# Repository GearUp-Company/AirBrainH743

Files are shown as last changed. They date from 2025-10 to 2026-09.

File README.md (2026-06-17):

<h1>
  <picture>
    <source media="(prefers-color-scheme: dark)" srcset="datasheet/Gearup_White.png">
    <source media="(prefers-color-scheme: light)" srcset="datasheet/Gearup.png">
    GearUp Logo
  </picture>
  AirBrainH743
</h1>

GearUp **AirBrain H743** flight controller. STM32H743VIH6 (480 MHz Cortex-M7), 36 × 31 × 10 mm, 8 g. Designed and made in Belgium.

This repository hosts the datasheet, pinouts, mechanical resources, and integration guides for the board. Source-of-truth for the product is the [Airbrain product page](https://takeyourgear.com/pages/products/airbrain).

<div align="center">

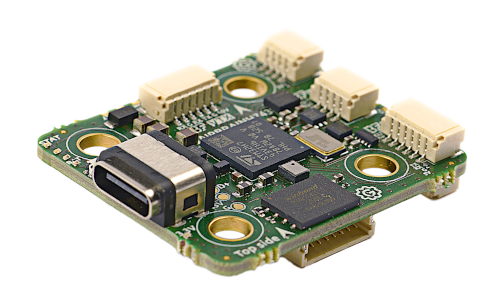
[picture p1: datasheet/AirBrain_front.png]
AirBrain_Front


</div>

## Firmware support

The AirBrain H743 is **officially supported upstream** by Betaflight, ArduPilot, and PX4. Targets live in each project's main branch.

| Stack | Target | Canonical source |
|---|---|---|
| **Betaflight** | `AIRBRAINH743` | Betaflight Configurator, Firmware Flasher, board dropdown |
| **ArduPilot** | `AIRBRAINH743` | Latest builds for [Copter](https://firmware.ardupilot.org/Copter/latest/AIRBRAINH743/), [Plane](https://firmware.ardupilot.org/Plane/latest/AIRBRAINH743/), [Rover](https://firmware.ardupilot.org/Rover/latest/AIRBRAINH743/), [Sub](https://firmware.ardupilot.org/Sub/latest/AIRBRAINH743/) |
| **PX4** | `gearup_airbrainh743_default` | [Latest CI build (.px4)](https://px4-travis.s3.amazonaws.com/Firmware/master/gearup_airbrainh743_default.px4) |

Boards ship pre-flashed with **Betaflight**.

INAV is in beta. Targets are present in this repo's `firmware/INAV/` folder for testing.

## Pinout & Datasheet

Latest datasheet and pinouts: [`/datasheet`](/datasheet).

<div align="center">

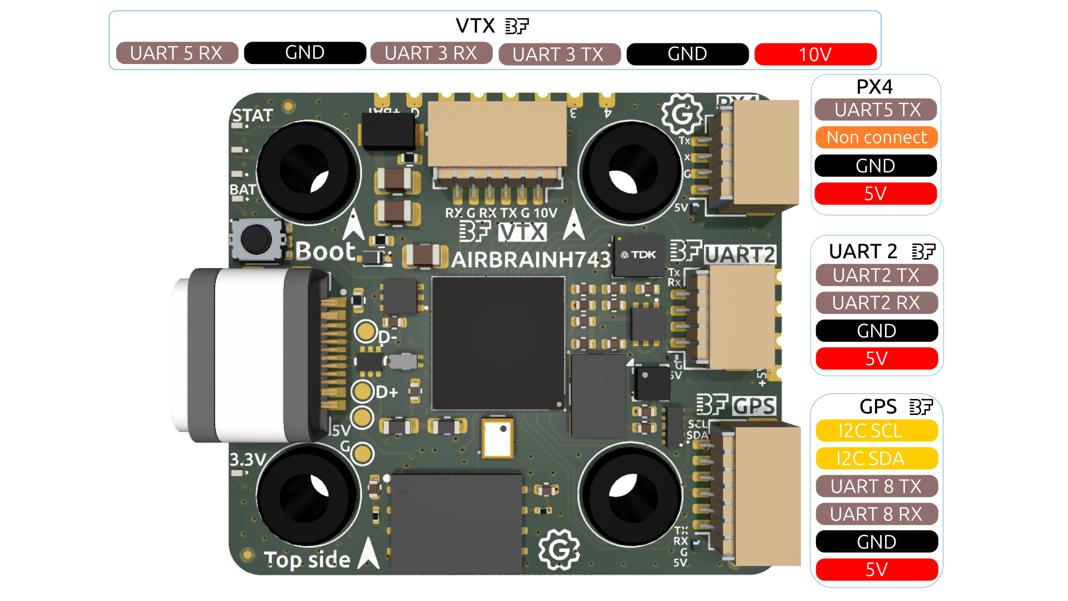
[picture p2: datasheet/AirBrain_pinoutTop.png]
AirBrain_Pinout_top

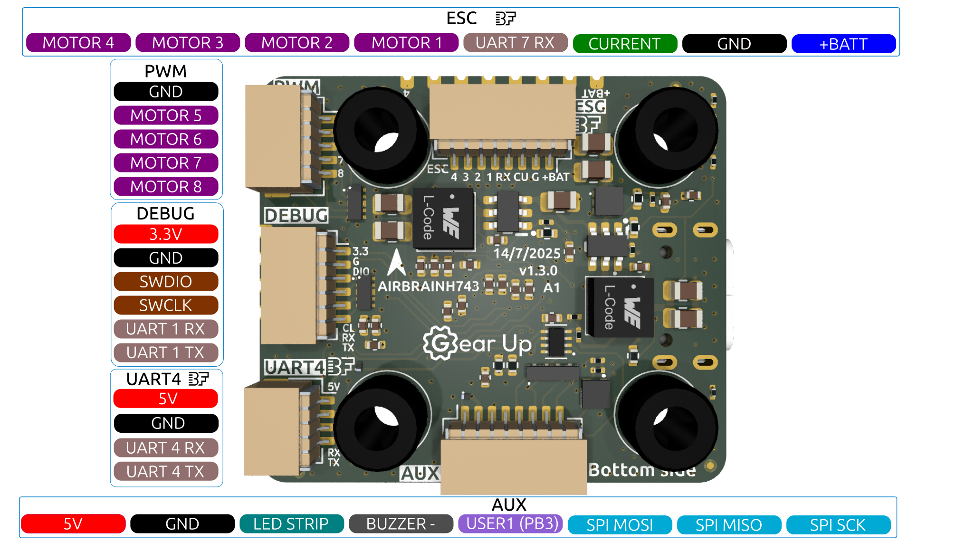
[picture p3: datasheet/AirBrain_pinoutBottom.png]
AirBrain_Pinout_bottom


</div>

## Switching firmware stacks

Boards ship with Betaflight. Switching to ArduPilot or PX4 is a one-time operation on a desktop computer. After switching, you can switch back with the same procedure.

### Entering DFU mode

DFU (Device Firmware Update) is the STM32's built-in ROM bootloader. It's required for the first install of any firmware family, for switching bootloaders (PX4, ArduPilot), and for recovery. Two routes into DFU:

- **Hardware (BOOT button)**: hold the on-board **BOOT** button while plugging in the USB cable. Release after the board enumerates. This route works regardless of which firmware is currently on the board, including a bricked board.
- **From Betaflight Configurator**: with Betaflight running, click **Activate Boot Loader** in the top right. The board reboots into DFU. *Only works while Betaflight is running.* If the board has ArduPilot or PX4 on it, use the BOOT button.

In DFU mode the board enumerates as a USB DFU device ("STM32 BOOTLOADER" or "DFU in FS Mode") and no longer responds as a serial device until you flash and exit.

---

### Betaflight, to ArduPilot

ArduPilot uses its **own bootloader** (different from Betaflight's monolithic flash layout). For a clean first install on an AirBrain that's running Betaflight, we recommend flashing the **with-bootloader** ArduPilot variant first; subsequent updates can use the no-bootloader `.apj` via Mission Planner over USB-MAVLink.

1. Go to [firmware.ardupilot.org/Copter/latest/AIRBRAINH743/](https://firmware.ardupilot.org/Copter/latest/AIRBRAINH743/) (replace `Copter` with `Plane`, `Rover`, `Sub`, etc. for your vehicle type).
2. Two files are published per release (vehicle-prefixed, e.g. `arducopter`, `arduplane`):
   - `<vehicle>_with_bl.hex`: contains the ArduPilot bootloader **and** firmware as a multi-region Intel HEX file. Use this for the first flash from a Betaflight board.
   - `<vehicle>.apj`: firmware only. Use this for over-MAVLink updates once the ArduPilot bootloader is on the board.
3. Put the AirBrain in **DFU mode** (BOOT button + USB).
4. Open **Mission Planner** (or QGroundControl).
5. Use the GCS's custom-firmware install option and select the `_with_bl.hex` file. Follow the on-screen prompts.
6. Wait for the flash to complete. The board reboots into ArduPilot.

For subsequent ArduPilot version bumps, you can connect the GCS to the running ArduPilot board over USB and flash the no-bootloader `.apj` directly.

---

### Betaflight, to PX4

PX4 uses its **own bootloader**, distinct from the Betaflight/ArduPilot bootloader. So switching to PX4 is a two-step flash: bootloader, then firmware.

#### Step 1: Flash the PX4 bootloader

Get the PX4 bootloader binary from this repo: [`firmware/PX4/bin/bootloader/gearup_airbrainh743_bootloader.bin`](firmware/PX4/bin/bootloader/gearup_airbrainh743_bootloader.bin).

Pick whichever flashing tool you're most comfortable with. The board needs to be in **DFU mode** for all three.

##### Option A: Betaflight Configurator (cross-platform, GUI)

Betaflight Configurator's Firmware Flasher can load any local `.bin` and write it via the STM32 ROM DFU. Works in both the desktop app and the web Configurator at [app.betaflight.com](https://app.betaflight.com).

1. Open Betaflight Configurator.
2. Put the AirBrain in DFU mode (see "Entering DFU mode" above).
3. Go to the **Firmware Flasher** tab.
4. Click **Load Firmware [Local]** and select `gearup_airbrainh743_bootloader.bin`.
5. Click **Flash Firmware**.

> Reported to work by upstream maintainers; not yet self-verified by GearUp end-to-end. If it fails, fall back to Option B (STM32CubeProgrammer) or Option C (dfu-util).

##### Option B: STM32CubeProgrammer (official ST tool, GUI, cross-platform)

[Download STM32CubeProgrammer](https://www.st.com/en/development-tools/stm32cubeprog.html) from ST.

1. Put the AirBrain in DFU mode.
2. Open STM32CubeProgrammer.
3. Connection dropdown (top right): select **USB**, then your DFU device, click **Connect**.
4. Click the **Erasing & Programming** tab on the left.
5. Browse to `gearup_airbrainh743_bootloader.bin`.
6. Set start address to `0x08000000`.
7. Click **Start Programming**.

##### Option C: dfu-util (CLI, Linux/macOS)

```sh
dfu-util -a 0 -s 0x08000000:leave \
  -D gearup_airbrainh743_bootloader.bin
```

#### Step 2: Flash the PX4 firmware

After flashing the bootloader, the board reboots and enumerates as a PX4 device. Two routes work, pick whichever fits your setup.

##### Option A: QGC Daily, Developer Build (recommended until PX4 v1.18 stable)

The AirBrain H743 target is on PX4 main branch but not yet in PX4 stable (v1.17). Until v1.18 lands, the cleanest route is QGC Daily, which auto-downloads the latest build from main.

1. Download QGC Daily from [docs.qgroundcontrol.com/Stable_V5.0/en/qgc-user-guide/releases/daily_builds.html](https://docs.qgroundcontrol.com/Stable_V5.0/en/qgc-user-guide/releases/daily_builds.html).
2. Open QGC Daily, go to **Vehicle Configuration, Firmware**, pick the USB port, click **Flash**.
3. Unplug and replug the USB cable when prompted.
4. Select **Advanced Settings**, choose **Developer Build (master)**.
5. QGC pulls the latest .px4 from PX4 main and flashes it.

After PX4 v1.18 stable releases (expected later in 2026), QGC Stable will pick the AirBrain target automatically. We will update this section then.

##### Option B: Manual download

For air-gapped systems or when you want a specific build pinned.

1. Download the latest PX4 firmware: [gearup_airbrainh743_default.px4](https://px4-travis.s3.amazonaws.com/Firmware/master/gearup_airbrainh743_default.px4). This is the official PX4 CI build, automatically rebuilt from PX4 main branch.
2. Open QGroundControl.
3. Connect the AirBrain via USB.
4. Use **Vehicle Setup, Firmware**, click **Advanced Settings**, choose **Custom firmware file**.
5. Select the .px4 file you downloaded.
6. Wait for the flash to complete.

> **Internal magnetometer note.** The LIS2MDL chip is detected by PX4 iis2mdc driver out of the box. PX4 dmesg should show iis2mdc #0 on I2C bus 1 address 0x1E rotation 2. No board-config change required. Verified 2026-06-16 with PX4 contributor Julian Oes.

---

### ArduPilot or PX4, back to Betaflight

Betaflight is a monolithic image flashed directly at `0x08000000` via STM32 ROM DFU. Going back from ArduPilot or PX4 wipes the previous bootloader and replaces it with Betaflight in one operation.

The "Activate Boot Loader" button in Betaflight Configurator only exists when Betaflight is already running. From ArduPilot or PX4 you must use the **hardware BOOT button** to enter DFU.

1. Put the AirBrain in DFU mode (hold BOOT button + plug in USB).
2. Open **Betaflight Configurator** (desktop app or web Configurator at [app.betaflight.com](https://app.betaflight.com)).
3. Go to the **Firmware Flasher** tab.
4. Select target `AIRBRAINH743` from the dropdown.
5. Pick the latest stable Betaflight release.
6. Check **Full chip erase** (recommended; clears any leftover ArduPilot bootloader area or PX4 NAND filesystem state).
7. Click **Load Firmware [Online]**, then **Flash Firmware**.

GearUp has a **cloud-build partnership integration in Betaflight Configurator**, so AirBrain targets are available in the official Configurator dropdown without any extra setup.

> **Offline recovery**: if Betaflight Configurator's online flasher is unavailable, the factory-default Betaflight binary is at [`firmware/Betaflight/bin/airbrain_h743_factory_recovery.bin`](firmware/Betaflight/bin/airbrain_h743_factory_recovery.bin). Recovery only, see that folder's [README](firmware/Betaflight/bin/README.md) for flashing instructions.

## ArduPilot integration notes

Common gotchas when running ArduPilot on the AirBrain H743, based on upstream maintainer feedback.

### ArduPilot 4.7 parameter rename, QGroundControl error

ArduPilot 4.7 renamed a large number of parameters. Notably, `ARMING_CHECK` was removed and replaced with `ARMING_SKIPCHK` (the meaning is inverted). QGroundControl has not yet been updated to recognise the new 4.7 parameter set, which surfaces as "missing parameter" errors after a fresh flash from the latest ArduPilot build.

Workaround: use the **beta version of Mission Planner**, which tracks the latest ArduPilot parameter set.

The AIRBRAINH743 target was added to ArduPilot after the stable-4.6 branch was cut, so the standard 4.6 stable downloads do not include AirBrain. The latest CI build is the canonical source.

### SBUS receiver on RX5 (UART5)

To run an SBUS receiver on the AirBrain's RX5 pin (UART5 in ArduPilot), disable RCIN on the default UART (UART2) and enable it on UART5:

```text
SERIAL2_PROTOCOL = -1
SERIAL5_PROTOCOL = 23
```

After setting these and rebooting, the RX5 pin will accept SBUS input.

## Building from source

If you want to build PX4, ArduPilot, or Betaflight firmware yourself, see [`BUILD.md`](BUILD.md). The repo's `firmware/<stack>/` folders contain target definitions and source where applicable, but **upstream is canonical**: please contribute target changes upstream.

## 3D files

The [`/3D`](/3D) folder contains a STEP file for the 30 × 30 to 20 × 20 mm mounting adapter.

Additional printable mounts, brackets, and housings are published on our **[MakerWorld page](https://makerworld.com/en/@GearUp)**.

## Repo layout

| Path | Contents |
|---|---|
| [`/datasheet`](/datasheet) | Latest datasheet PDF + pinout images |
| [`/firmware/PX4/bin/bootloader/`](/firmware/PX4/bin/bootloader/) | PX4 bootloader binary |
| [`/firmware/PX4/sourcecode/`](/firmware/PX4/sourcecode/) | PX4 target source (mirror of upstream) |
| [`/firmware/Ardupilot/`](/firmware/Ardupilot/) | ArduPilot target source (mirror of upstream) |
| [`/firmware/Betaflight/`](/firmware/Betaflight/) | Betaflight target source (mirror of upstream) + factory-default `.bin` for offline recovery |
| [`/3D`](/3D) | STEP file for 30 × 30 to 20 × 20 mounting adapter |
| [`BUILD.md`](BUILD.md) | Build-from-source guide for all three firmware families |
| [`LICENSE.md`](LICENSE.md) | License terms |

## License

See [`LICENSE.md`](LICENSE.md).

## Contact

- Website: [takeyourgear.com](https://takeyourgear.com/)
- Email: [info@takeyourgear.com](mailto:info@takeyourgear.com)
- Issues: please use this repo's [Issues](https://github.com/GearUp-Company/AirBrainH743/issues) for documentation and integration questions

<div align="center">

AirBrain Logo
AirBrain Logo

</div>

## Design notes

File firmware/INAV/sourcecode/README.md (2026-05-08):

<!--
NOT a snapshot of upstream. INAV target for AIRBRAINH743 has not been merged into iNavFlight/inav as of 2026-05-08.
These files are GearUp's local target definition, used to produce the beta INAV builds in `firmware/INAV/bin/`.
-->

# INAV target source for AIRBRAINH743

**Status: beta, not upstreamed.** As of 2026-05-08, the AIRBRAINH743 INAV target has not been merged into [iNavFlight/inav](https://github.com/iNavFlight/inav). The files in this folder are GearUp's local target definition, used to produce the beta builds in [`firmware/INAV/bin/`](../bin/).

If and when the target is merged upstream, this folder will be refreshed from `iNavFlight/inav` and this README replaced with a snapshot pointer.

## Files

| File | Purpose |
|---|---|
| `target.h` | Pin map and feature flags |
| `target.c` | Timer / DMA / pin assignments |
| `config.c` | Default INAV configuration |
| `CMakeLists.txt` | INAV build target wiring |

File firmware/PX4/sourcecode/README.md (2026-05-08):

<!--
Snapshot of upstream PX4 board folder, refreshed 2026-05-08.
Canonical source: https://github.com/PX4/PX4-Autopilot/tree/main/boards/gearup/airbrainh743
Refresh: cp from upstream sparse-checkout of `boards/gearup/airbrainh743/` (extras/ omitted, see below).
-->

# PX4 target source for `gearup_airbrainh743`

**Snapshot of upstream**, refreshed 2026-05-08 from [`PX4/PX4-Autopilot`](https://github.com/PX4/PX4-Autopilot) at commit `78abda4`.

## Canonical source

The PX4-Autopilot repo is the source of truth:

- Repo: [github.com/PX4/PX4-Autopilot](https://github.com/PX4/PX4-Autopilot)
- Path: [`boards/gearup/airbrainh743/`](https://github.com/PX4/PX4-Autopilot/tree/main/boards/gearup/airbrainh743)

## Folder structure

| Path | Purpose |
|---|---|
| `bootloader.px4board` | Build config, bootloader target |
| `default.px4board` | Build config, default firmware target |
| `firmware.prototype` | Firmware metadata template |
| `init/` | Board startup scripts (`rc.board_defaults`, `rc.board_sensors`, `rc.board_extras`) |
| `nuttx-config/` | NuttX RTOS configuration (defconfig, board.h, linker scripts) |
| `src/` | Board-specific C/C++ (init, USB, SPI, I2C, LED, timer config, hw config) |

## Bootloader binary, version note

Upstream's `extras/gearup_airbrainh743_bootloader.bin` is **not mirrored here** to avoid carrying two copies of the bootloader at different versions.

The bootloader binary actively distributed for the AirBrain is at [`firmware/PX4/bin/bootloader/gearup_airbrainh743_bootloader.bin`](../bin/bootloader/gearup_airbrainh743_bootloader.bin). It is built post-PR-27227 (NAND fix) and is bit-identical to the build distributed by Julian Oes.

## How to refresh

```sh
git clone --depth 1 --filter=blob:none --sparse https://github.com/PX4/PX4-Autopilot.git
cd PX4-Autopilot && git sparse-checkout add boards/gearup/airbrainh743
# Copy boards/gearup/airbrainh743/* (except extras/) over this folder.
```

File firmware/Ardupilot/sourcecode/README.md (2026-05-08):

<!--
Snapshot of upstream ArduPilot board folder, refreshed 2026-05-08.
Canonical source: https://github.com/ArduPilot/ardupilot/tree/master/libraries/AP_HAL_ChibiOS/hwdef/AIRBRAINH743
Refresh: cp from upstream sparse-checkout of `libraries/AP_HAL_ChibiOS/hwdef/AIRBRAINH743/`
-->

# AIRBRAINH743 Flight Controller

The AIRBRAINH743 is a flight controller designed and produced by [Gear Up](https://takeyourgear.com/).

## Features

- MCU - STM32H743xx 32-bit processor running at 480 MHz
- IMU - Invensense ICM-42688-P
- Barometer - DPS368
- Magnetometer - LIS2MDL
- 128 Mbytes flash-based logging
- Battery input voltage: 3S-10S
- BEC 5V 2A
- BEC 10V 2.5A
- 7x UARTs
- 9x PWM Outputs (8 Motor Output, 1 LED)

## Pinout

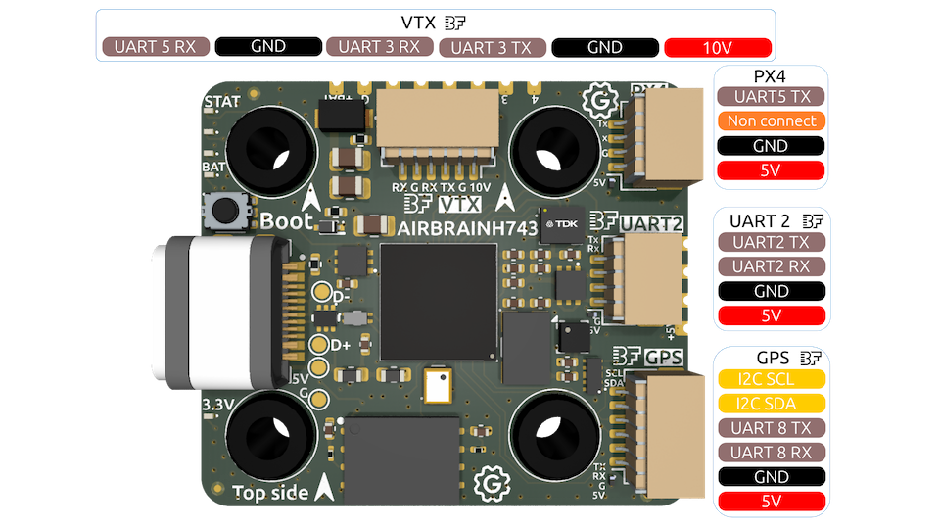
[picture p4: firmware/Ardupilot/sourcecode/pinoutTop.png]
AIRBRAINH743 Board Top AIRBRAINH743 Top
 
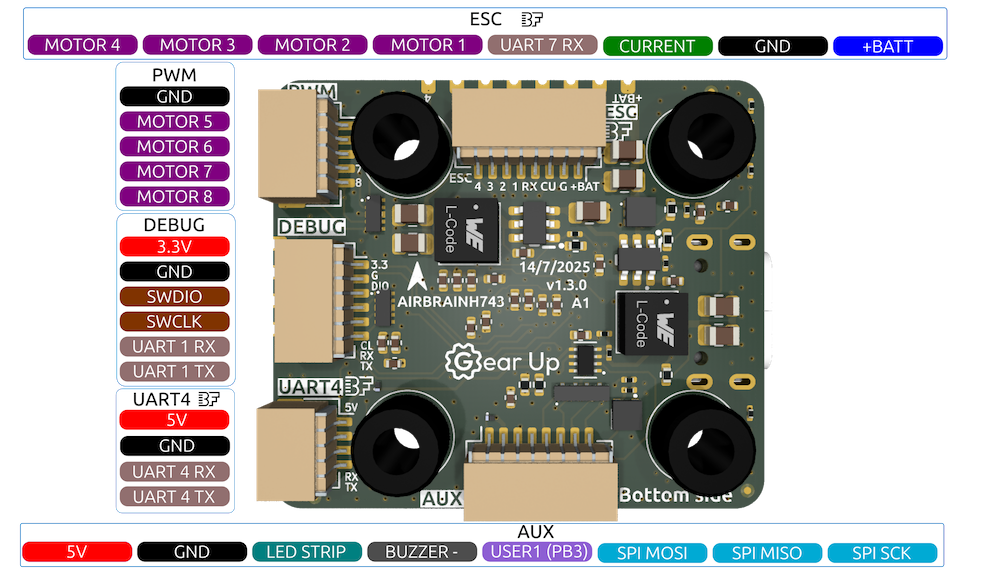
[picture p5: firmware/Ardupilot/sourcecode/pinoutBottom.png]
AIRBRAINH743 Board Bottom AIRBRAINH743 Bottom
 

## UART Mapping

The UARTs are marked RX and TX in the above pinouts. The RX pin is the
receive pin. The TX pin is the transmit pin .

- SERIAL0 -> USB (MAVLink2)
- SERIAL1 -> USART1 (None)
- SERIAL2 -> USART2 (RCIN, DMA-enabled)
- SERIAL3 -> USART3 (MSP DisplayPort, DMA-enabled)
- SERIAL4 -> UART4 (GPS, DMA-enabled)
- SERIAL5 -> UART5 (None, DMA-enabled)
- SERIAL7 -> UART7 (ESCTelemetry)
- SERIAL8 -> UART8 (GPS2, DMA-enabled)

## RC Input

The default RC input is configured on USART2. RC could  be applied instead to a different UART port,  and set
the protocol to receive RC data `SERIALn_PROTOCOL` = 23 and change [SERIAL2_PROTOCOL](https://ardupilot.org/copter/docs/parameters.html#serial2-protocol-telemetry-2-protocol-selection)
to something other than '23'. For rc protocols other than unidirectional, the USART2_TX pin will need to be used:

- FPort would require [SERIAL2_OPTIONS](https://ardupilot.org/copter/docs/parameters.html#serial2-options-telem2-options) be set to "15".
- CRSF would require [SERIAL2_OPTIONS](https://ardupilot.org/copter/docs/parameters.html#serial2-options-telem2-options) be set to "0".
- SRXL2 would require [SERIAL2_OPTIONS](https://ardupilot.org/copter/docs/parameters.html#serial2-options-telem2-options) be set to "4" and connects only the TX pin.

The HD VTX connector contains UART5 RX for SBUS. To use this connector for SBUS set [SERIAL2_PROTOCOL](https://ardupilot.org/copter/docs/parameters.html#serial2-protocol-telemetry-2-protocol-selection)
to something other than '23' and set [SERIAL5_PROTOCOL](https://ardupilot.org/copter/docs/parameters.html#serial5-protocol-serial5-protocol-selection) to '23'

## PWM Output

The AIRBRAINH743 supports up to 9 PWM or DShot outputs. The pads for motor output
M1 to M9 are provided on both the motor connectors and on separate pads, plus
separate pads for LED strip and other PWM outputs.

The PWM is in 4 groups:

- PWM 1-4   in group1
- PWM 5-6   in group2
- PWM 7-8   in group3
- PWM 9   in group4 (defaulted to Serial LED protocol)

Channels within the same group need to use the same output rate. If
any channel in a group uses DShot then all channels in the group need
to use DShot. Channels 1-8 support bi-directional dshot.

## Battery Monitoring

The board has a internal voltage sensor and connections on the ESC connector for an external current sensor input.
The voltage sensor can handle up to 6S LiPo batteries.

The default battery parameters are:

- BATT_MONITOR = 4
- BATT_VOLT_PIN = 4
- BATT_CURR_PIN = 8
- BATT_VOLT_MULT =1 5.0
- BATT_AMP_PERVLT = 101.0

## Compass

The AIRBRAINH743 has builtin compass. You can also attach an external compass using I2C on the SDA and SCL pads.

## Loading Firmware

Firmware for these boards can be found [here](https://firmware.ardupilot.org) in sub-folders labeled "AIRBRAINH743".

Initial firmware load can be done with DFU by plugging in USB with the
bootloader button pressed. Then you should load the "with_bl.hex"
firmware, using your favourite DFU loading tool.

Once the initial firmware is loaded you can update the firmware using
any ArduPilot ground station software. Updates should be done with the
*.apj firmware files.

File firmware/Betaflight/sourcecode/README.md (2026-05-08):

# Betaflight target source

**Snapshot of upstream**, refreshed 2026-05-08 from [`betaflight/config`](https://github.com/betaflight/config) at commit `b13b54c`.

## Canonical source

The Betaflight unified-targets repo is the source of truth:

- Repo: [github.com/betaflight/config](https://github.com/betaflight/config)
- Path: [`configs/AIRBRAINH743/config.h`](https://github.com/betaflight/config/blob/master/configs/AIRBRAINH743/config.h)

## Files

| File | Purpose |
|---|---|
| `config.h` | Unified-target definition for AIRBRAINH743 (pin map, default features, voltage/current scaling) |

## How to refresh

```sh
curl -L -o config.h \
  https://raw.githubusercontent.com/betaflight/config/master/configs/AIRBRAINH743/config.h
```

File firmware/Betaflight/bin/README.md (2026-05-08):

# Betaflight binaries

## Canonical source

For day-to-day flashing, **use Betaflight Configurator's online firmware flasher**. Select target `AIRBRAINH743` from the dropdown and pick the latest stable release. GearUp's cloud-build partnership integration in Betaflight Configurator provides AirBrain targets without any extra setup.

## Files in this folder

### `airbrain_h743_factory_recovery.bin`

**Recovery only.** This is the factory-default Betaflight binary GearUp flashes at manufacturing. It is here as an offline fallback in case Betaflight Configurator's online flasher is unavailable or you need to reset the board to its as-shipped state.

- Format: raw `.bin`, flash to address `0x08000000` via STM32 ROM DFU.
- Flash via dfu-util:

  ```sh
  sudo dfu-util -a 0 --dfuse-address 0x08000000:leave \
    -D airbrain_h743_factory_recovery.bin
  ```

- Or via Betaflight Configurator's **Load Firmware [Local]** option in DFU mode.
- Or via STM32CubeProgrammer.

This file is not version-bumped on every Betaflight release. The Betaflight Configurator online flasher always has the latest. Only use this binary when the online path is not an option.

### `betaflight_4.5.3_STM32H743_AIRBRAINH743_49d7ad3e.hex`

Historical reference, Betaflight 4.5.3 build. Same caveat as above: the Betaflight Configurator online flasher is the canonical source for current builds.

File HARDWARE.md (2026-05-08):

# AirBrain H743 hardware overview

This document is a quick orientation. The full electrical, mechanical, and pinout reference is in the [datasheet PDF](datasheet/Datasheet_AirBrain.pdf).

## At a glance

| | |
|---|---|
| **MCU** | STM32H743VIH6, 480 MHz Cortex-M7, 2 MB Flash, 1 MB RAM |
| **IMU** | InvenSense ICM-42688-P, 6-axis, clock-synchronised |
| **Magnetometer** | STMicroelectronics LIS2MDL |
| **Barometer** | Infineon DPS368 |
| **Logging** | Winbond W25N01GVZEIT, 128 MB on-board NAND |
| **Connectivity** | USB-C (GCT USB4730-GF-A-KIT, IP67 panel-mount with gasket) |
| **Power** | 3S to 10S input, switching-IC topology, BEC 5V 2A + BEC 10V 2.5A |
| **UARTs** | 7 |
| **PWM outputs** | 9 (8 motor outputs, 1 LED) |
| **Form factor** | 36 × 31 × 10 mm, 8 g, 20 × 20 mm mounting (30 × 30 adapter STEP in `/3D`) |
| **USB** | USB-C panel-mount with gasket, IP67 connector spec |
| **Origin** | Designed and assembled in Belgium |

## What this board is for

Universal flight controller for UAVs and small autonomous platforms where a single hardware target needs to flash any of the three major open-source flight stacks (Betaflight, ArduPilot, PX4) without forking firmware.

Common platforms: race cine FPV, autonomous mapping, fixed-wing inspection, indoor research drones, robotic vehicles using ArduPilot Rover, ROV builds using ArduSub.

## Per-firmware target name

| Stack | Target |
|---|---|
| Betaflight | `AIRBRAINH743` |
| ArduPilot | `AIRBRAINH743` |
| PX4 | `gearup_airbrainh743_default` |

See the [Switching firmware stacks](README.md#switching-firmware-stacks) section of the README for end-to-end transition workflows.

## Per-firmware default behaviour

Status LED, ESC protocol defaults, UART role mapping, and LED Strip behaviour differ per firmware. The datasheet documents defaults per stack; the integrator can remap any of these via the stack's configurator.

## Compatibility

- **ESCs**: BLHeli_32 / AM32 over DShot150/300/600/1200, bidirectional DShot supported on M1 to M8.
- **Receivers**: any UART-based serial protocol (CRSF, ELRS, SBUS, F.Port, SRXL2). PPM and parallel PWM RX are legacy formats and not the recommended integration path on this board.
- **OSD**: no on-board OSD chip.
  - **Analog video, plug-and-play**: use a VTX with built-in OSD such as the [TBS Unify EVO](https://www.team-blacksheep.com/products/prod:unify_evo). Self-contained graphics; CRSF link-data overlay (RSSI / LQ / SNR / TX power) works when the FC has a CRSF-speaking RX wired in (ELRS, Crossfire, Ghost). "CRSF" here is the FC-to-VTX wire protocol, the VTX has no RF receiver. Compatible with MAVLink GCS telemetry on a separate UART.
  - **Analog video, FC-rendered OSD**: add an inline MAX7456 / AT7456E OSD module to overlay the firmware's native OSD elements (battery voltage, GPS, BF-style elements).
  - **HD video**: use a digital VTX (DJI, Walksnail, HDZero) over MSP DisplayPort.
- **GPS**: any UART-based GPS module.
- **Telemetry**: MAVLink (ArduPilot, PX4) on any UART. ESC telemetry on UART7 (default across Betaflight, ArduPilot, and PX4).

## Physical reference

| Dimension | Value |
|---|---|
| PCB outline | 36 × 31 mm |
| Stack height | 10 mm |
| Mounting pattern | 20 × 20 mm, M2 |
| 30 × 30 adapter | STEP file in [`/3D`](/3D), printable in any FDM resin |
| Connector face | One short edge (USB-C, motor connectors), opposite edge has BOOT button + RGB LED |

For the full pinout (numbered pads + colour-legend), see the [datasheet PDF, page 2](datasheet/Datasheet_AirBrain.pdf).

## Compliance posture

- **CE conformity** declared by EUnify BV (manufacturer declaration model). Integrator declares for the final UAV.
- **Pre-compliance EMC** sweeps run at Würth Elektronik eiSos lab before each board revision.
- **NDAA** compliant on the bill of materials (EU/US/JP/TW component sourcing).
- **Origin** Belgium (designed + final assembly + functional test).

For the formal Declaration of Conformity, contact [info@takeyourgear.com](mailto:info@takeyourgear.com).

## More

- [Datasheet PDF](datasheet/Datasheet_AirBrain.pdf), full electrical + mechanical reference
- [README](README.md), firmware-stack switching guide and integrator workflows
- [BUILD.md](BUILD.md), build-from-source guide for all three firmware families
- [LICENSE.md](LICENSE.md), license terms

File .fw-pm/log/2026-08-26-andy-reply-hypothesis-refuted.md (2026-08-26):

# 2026-08-26: Andy Piper reply, contention hypothesis refuted

Reply within 8 minutes (DM): "on an H7 the _UP channel and _CH channels
are shared. There should be no contention." + "per timer".

Meaning: on H743, each timer's UP and CH DMA channels are one shared
resource per timer, so DMA_NOSHARE on the UP streams already isolates the
capture side. Consequences:
- capture-stream DMA contention is NOT a plausible group-loss path (refuted
  by subsystem maintainer);
- no hwdef change warranted (CH streams in noshare = no-op);
- group-collapse machinery (stuck dshot_state) remains, but trigger must be
  elsewhere; probability shifted toward non-software causes (ESC desync,
  power/wiring per arm, telemetry glitch).

Investigation fully blocked on customer data: .param (bdshot yes/no) + two
crash logs (RCOU commanded-vs-actual). Requested by mail 2026-08-26.

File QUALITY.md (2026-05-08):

# AirBrain H743 quality

## End-of-line functional test

Every AirBrain H743 board is functionally tested before shipping. The test verifies:

- **Power rails**: VBat to 5V BEC and VBat to 10V BEC, both verified under load.
- **MCU programmability**: a Betaflight build is flashed via DFU, success of the flash is verified.
- **UART communication**: serial communication on the active UART is exercised end-to-end.
- **Motor outputs**: outputs M1 to M4 are verified for correct switching behaviour.

A board that does not pass every step on the test fixture does not ship.

## EMC

Pre-compliance EMC sweeps are run at the [Würth Elektronik eiSos](https://www.we-online.com/) lab in Belgium before each board revision. Sweeps cover radiated emissions and conducted emissions per the EN 55032 / EN 55035 reference, in the configurations relevant to the AirBrain's deployment profile.

Specific test report content is held under confidentiality with Würth and is not republished. The test ticket reference for the current revision is available on request from [info@takeyourgear.com](mailto:info@takeyourgear.com) for procurement and integration evaluators.

## ESD

Every external connector on the AirBrain H743 carries ESD protection on the signal lines. The board survives realistic ESC / VTX / RX coexistence, not just bench-perfect conditions.

## Bill of materials

The component bill of materials is sourced exclusively from authorised distributors in EU / US / JP / TW countries. The supply origin is **NDAA-compliant**.

## Conformal coating

Conformal coating is **not applied by default** on standard production AirBrain H743 boards.

Conformal coating is **available as a paid extra** for orders that meet a minimum order quantity. The coating type, masked areas, and MOQ are agreed per order. Contact [info@takeyourgear.com](mailto:info@takeyourgear.com) with the application context (humidity profile, salt fog, dielectric requirement) for a quote.

## Warranty

The standard warranty period is **24 months from date of shipment** for defects in materials and workmanship under normal operating conditions. Warranty is fulfilled by replacement of the defective board.

For B2B and OEM orders, warranty terms are contractually defined per order; the 24-month period is the default unless otherwise agreed.

Out of scope: physical damage from crash, water ingress (the AirBrain is IP67 only as a connector with proper gasket installation, not as a board), reverse polarity, over-voltage beyond the specified 3S to 10S input range, and modifications.

## Origin

The AirBrain H743 is **designed in Belgium and assembled in Belgium**. Final functional test is performed at our facility before shipment.

## Contact

Quality questions, conformal-coating quotes, EMC test ticket reference, or warranty claims:

- [info@takeyourgear.com](mailto:info@takeyourgear.com)
- For quality issues on a unit, include the order reference and a description of the failure mode.

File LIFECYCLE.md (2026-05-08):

# AirBrain H743 lifecycle commitments

## Production and availability

For **multi-year procurement programmes**, defence or institutional contracts requiring assured supply, please contact us directly. We can discuss private letter-of-supply, MOQ-backed reservations, and component-buffer arrangements on a case-by-case basis.

## End-of-life notice

If we plan to discontinue the AirBrain H743, we commit to:

- **6 months minimum advance notice** before the last-time-buy window closes.
- A **last-time-buy window of 3 months** during which integrators can place final stocking orders.
- A **public end-of-life announcement** posted to this repository (LIFECYCLE.md update + GitHub release tagged `eol-airbrain-h743`).

## Firmware-update commitment

We commit to:

- **Maintaining the upstream AIRBRAINH743 / `gearup_airbrainh743_default` targets** in Betaflight (`betaflight/config`), ArduPilot (`ardupilot/ardupilot`), and PX4 (`PX4/PX4-Autopilot`) as long as the board is in active production.
- **Reviewing, testing, and contributing fixes upstream** when AirBrain-specific issues are reported.
- **Not forking or maintaining a private firmware branch.** All AirBrain firmware lives in the public upstream projects. If upstream support for the STM32H743 line is dropped at the project level (we do not anticipate this), we will assess and communicate alternatives at that point.

After end-of-life, the upstream targets remain available indefinitely from the upstream projects. We do not commit to actively backporting fixes after EOL but the targets do not disappear.

## Hardware-revision policy

- **All hardware revisions are documented** in the datasheet's Hardware changelog (page near the back of the PDF).
- **Pinout, mounting pattern, and connector positions are stable across revisions** within a major hardware version (v1.x). A pinout or connector change triggers a major version bump (v2.0).
- **BOM changes for component-availability reasons** (e.g. a passive supplier substitution) are not considered revisions and are not separately announced.
- **Functional changes** (added feature, dropped feature, performance shift) are documented and announced via this LIFECYCLE.md and a GitHub release.

## Spares and repair

The AirBrain H743 is not designed as a field-repairable unit. Replacement boards are the standard remedy for a defective unit under warranty. Outside warranty, replacement boards remain orderable as long as the board is in production.

The following accessories are orderable separately:

- JST-SH cables (replacement, in the lengths supplied with the board).
- M3 silicone soft-mounting standoffs.

We do not stock individual electronic components for field repair.

## Contact

Lifecycle questions, multi-year programme inquiries, or formal letter-of-supply requests:

- [info@takeyourgear.com](mailto:info@takeyourgear.com)
- Mention "AirBrain lifecycle" in the subject

For urgent supply-continuity discussions tied to a defence or institutional programme, mention the programme name and timeline in the first email so we can route appropriately.

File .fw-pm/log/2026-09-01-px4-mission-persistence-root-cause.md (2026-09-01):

# PX4 mission persistence: root cause found (2026-09-01)

**Reported by:** LuxUAV, PX4 1.18.0 build 80, git `e8ea98b`, built 2026-08-18.
Mission uploads and executes correctly; full sequence Mission -> RTL -> auto
landing flown. After a full power-down (battery disconnect) the mission is gone
and must be re-uploaded. NAND/littlefs is healthy: `.ulg` logging writes fine.

## Root cause (code-read, verified at source)

`boards/gearup/airbrainh743/init/rc.board_defaults`:

```
# Store missions in RAM
param set-default SYS_DM_BACKEND 1
```

- `SYS_DM_BACKEND` enum, `src/modules/dataman/parameters.yaml`: `-1` disabled,
  `0` default storage (file on persistent storage), `1` RAM. **PX4 default is 0.**
- `DATAMAN_PERSISTENT_STORAGE`, `src/modules/dataman/Kconfig`: `default y`.
  airbrainh743 does not disable it, so the persistent path IS available.
- Introduced by commit `2df92cc` (Julian Oes, 2026-04-22) inside a logger-tuning
  commit. Stated reason: "no SD on this board". True, but the board has
  persistent storage as littlefs on W25N NAND, which the customer's own working
  logging proves.

## Assessment

Defect in our board default. Not a PX4 bug, not customer error. Affects every
AirBrain PX4 user who flies missions. Not billable work.

## Not yet verified

The fix is a code-read diagnosis. `SYS_DM_BACKEND 0` has NOT been bench-tested on
our hardware, and the reason RAM was chosen may go beyond "no SD" (NAND write
pattern, wear, or a bring-up issue not recorded in the commit message).

## Next

1. Ask Julian Oes why RAM, before changing his default upstream.
2. Bench: set `SYS_DM_BACKEND 0`, reboot, upload mission, full power cycle,
   confirm persistence AND that logging still works.
3. If clean: one-line board-default change plus upstream PR under the phase_9
   gate (build-verify, CONTRIBUTING at source, strip internal provenance).

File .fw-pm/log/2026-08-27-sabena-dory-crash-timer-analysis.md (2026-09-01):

# Sabena "Dory" crash-log analysis — TIM-timer hypothesis TESTED and REJECTED

Date: 2026-08-27. Target: AIRBRAINH743 / ArduPilot 4.8.0-dev. Log: "2026-08-14 14-05-10.bin" (Sabena, delivered 2026-08-27). Analyst: fw-pm.

## Question
Is the in-flight output failure caused by a TIM timer / DMA output-group fault on the AirBrain, per the 26/08 hypothesis (outputs grouped TIM1=1-4, TIM3=5-6, TIM2=7-8)?

## Conclusion: NO. Single-channel thrust loss on output ch2 (frame Motor 5). FC output stage exonerated.

## Evidence
1. hwdef groups: TIM1=out1-4, TIM3=out5-6, TIM2=out7-8. Config: OCTA-X, MOT_PWM_TYPE=5 (DShot600), bidir DShot all 8 (BDMASK=255), so per-motor RPM telemetry available.
2. Primary event: ERR subsys=25 THRUST_LOSS_CHECK ecode=1 at t=185.1s — FIRST error, BEFORE any EKF/compass error.
3. Commanded (RCOU) vs actual (ESC RPM), failure window 185-190s:
   - out ch2 RPM collapses ~7900 -> ~3200 from 186.0s; FC then pins ch2 to min (1150).
   - out ch1, ch3, ch4 (SAME TIM1 group as ch2) stay HEALTHY, RPM tracks command throughout.
   - out ch6 "alternates" but RPM TRACKS command (1906->8857, 1150->4714): healthy motor, FC control oscillation, not a fault.
4. Bidir DShot telemetry from ch2's ESC CONTINUES at full rate through the failure (70 msgs 185-190s, same as healthy chans), reporting real low RPM. A TIM1 DMA/signal fault would stop the ESC frames and thus the telemetry. It did not.
5. Cascade: thrust loss (185.1) -> attitude fight -> EKF Failsafe (189.8) + mag-field error (xy diff 277>100, consistent with erratic current disturbing compass) + GPS glitch -> disarm ~193s.

## Why not a timer: ch1/ch2/ch3/ch4 share TIM1 (burst-DShot shares TIM1_UP DMA). A timer/DMA fault fails the whole group together. Only ch2 failed; ch1/ch3/ch4 stayed healthy. A shared-timer group cannot drop one channel and keep three.

## Most likely root cause (downstream of FC, on output ch2 = frame Motor 5): ESC desync or motor/prop/mechanical thrust loss on that single channel. ESC alive + reporting + motor underperforming command == classic desync/mechanical signature.

## Caveats / to confirm
- One crash log analysed (14-05-10). Earlier report mentioned a second incident; request/analyse its log too.
- Confirm on Sabena side: inspect ch2 motor/ESC/prop/solder; check for desync markers; frame config (FRAME_CLASS=4 OCTA but out7-8 show 0 RPM / no telemetry — only 6 active motors, worth confirming).

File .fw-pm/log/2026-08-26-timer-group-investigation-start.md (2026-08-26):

# 2026-08-26: timer-group crash investigation opened

Trigger: customer on-site meeting 26/08. Two in-flight incidents on an
octocopter running ArduCopter 4.7.0: once motors 5-6 stopped, once motors
7-8, never motors 1-4. Customer hypothesis: software issue tied to timer
groups.

Verified in ardupilot clone (master 1ea89b0, hwdef/AIRBRAINH743/hwdef.dat):
M1-M4 = TIM1 CH1-4 (BIDIR on M1, M3); M5-M6 = TIM3 CH3/CH4 (BIDIR M5);
M7-M8 = TIM2 CH3/CH4 (BIDIR M7); M9 = TIM5_CH3.
DMA_NOSHARE and DMA_PRIORITY both list TIM1_UP TIM3_UP TIM2_UP SPI1*.
Grouping matches the customer's description exactly: incidents sit in the
two non-TIM1 groups.

Actions: upstream sweep agent launched (GitHub issues, Discourse, 4.6/4.7
RCOutput/DShot changes). Crash logs + .param requested from customer.
Dev-check question drafted after sweep results, customer anonymized.

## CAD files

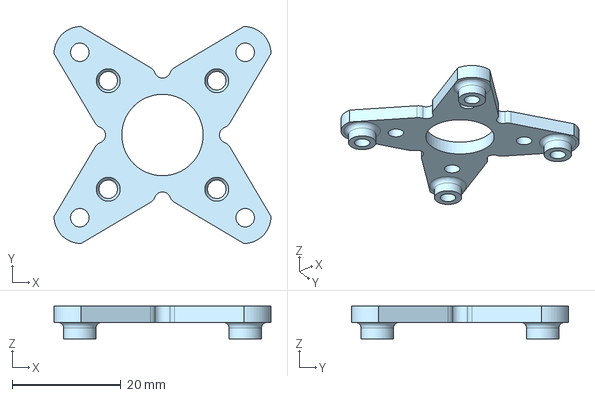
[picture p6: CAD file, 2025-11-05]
3D/30x30_to_20x20_short.step
40.0 x 40.0 x 6.00 mm

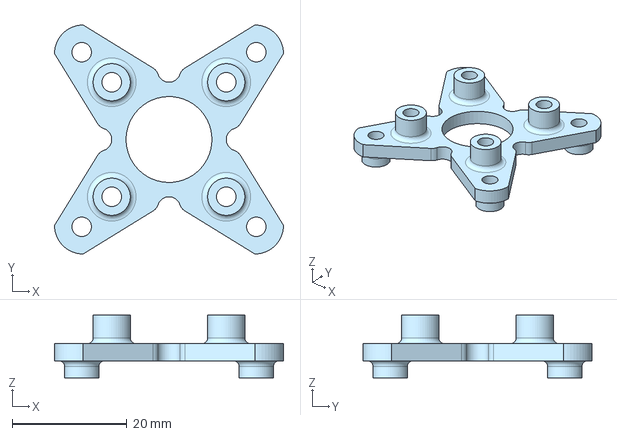
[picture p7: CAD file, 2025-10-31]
3D/30x30_to_20x20.step
40.0 x 40.0 x 11.0 mm

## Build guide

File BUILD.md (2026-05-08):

# Building firmware for AirBrain H743

Pre-built firmware for the AirBrain H743 is available from each upstream project's official channels (links below per firmware family). Build from source if you need:

- A custom firmware version (apply your own patches, integrate with proprietary modules)
- A bleeding-edge build between official upstream releases
- A specific feature flag combination not covered in the official build

This page documents the per-family target strings, upstream config paths, and AirBrain-specific notes. For full build environment setup (toolchains, dependencies), refer to each upstream project's own build documentation.

## ArduPilot

- **Target string**: `AIRBRAINH743`
- **Upstream hwdef**: https://github.com/ArduPilot/ardupilot/tree/master/libraries/AP_HAL_ChibiOS/hwdef/AIRBRAINH743
- **Build (after standard ArduPilot environment setup)**:

  ```
  ./waf configure --board AIRBRAINH743
  ./waf copter
  ```

- Build other vehicle types by substituting the second command (`./waf plane`, `./waf rover`, `./waf sub`).
- **Official pre-built binaries**: https://firmware.ardupilot.org/Copter/latest/AIRBRAINH743/
- **Help**: ArduPilot Discuss (https://discuss.ardupilot.org), GitHub Issues on this repo.

Reference: ArduPilot build docs at https://ardupilot.org/dev/docs/building-the-code.html

## PX4

- **Target string**: `gearup_airbrainh743_default`
- **Upstream board definition**: https://github.com/PX4/PX4-Autopilot/tree/main/boards/gearup/airbrainh743
- **Build (after standard PX4 environment setup)**:

  ```
  make gearup_airbrainh743_default
  ```

- **Official pre-built binaries**: https://docs.px4.io/main/en/flight_controller/gearup_airbrainh743 (links to firmware download)
- **In-repo reference binary**: `firmware/PX4/bin/gearup_airbrainh743_default.px4`. Built from PX4 main post-PR-27227 (NAND bad block management fix). See [UPGRADING.md](firmware/PX4/UPGRADING.md) for the `mklittlefs` step required when upgrading from a pre-PR-27227 build.
- **Help**: PX4 Discuss (https://discuss.px4.io), GitHub Issues on this repo.

Reference: PX4 build docs at https://docs.px4.io/main/en/dev_setup/building_px4.html

## Betaflight

- **Target string**: `AIRBRAINH743`
- **Upstream config** (modern, Betaflight 4.5+): https://github.com/betaflight/config/tree/master/configs/AIRBRAINH743
- **Pre-built binaries**: select `AIRBRAINH743` in the Betaflight Configurator board dropdown at https://app.betaflight.com. The Configurator downloads the pre-built binary automatically.
- **Documentation**: https://www.betaflight.com/docs/wiki/boards/current/AIRBRAINH743
- **Help**: Betaflight Discord (link from https://betaflight.com), GitHub Issues on this repo.

Reference: Betaflight build docs at https://github.com/betaflight/betaflight/blob/master/README.md

## Where to file issues

For AirBrain-specific issues (target config, board behaviour, hardware integration), use this repo's issue tracker: https://github.com/GearUp-Company/AirBrainH743/issues

For upstream firmware bugs (regardless of AirBrain), file in the relevant upstream project. We track upstream changes that affect the AirBrain target and update this repo's binaries accordingly.

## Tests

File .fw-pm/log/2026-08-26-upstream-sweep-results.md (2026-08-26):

# 2026-08-26: upstream sweep results (agent, 39 tool-uses, all URLs in entry)

Well-supported negative: NO upstream issue describes in-flight loss of
exactly one timer group on H743 in 4.6/4.7. 4.7.0 contains every known
DShot/DMA fix (incl. PR 31398 cache flush/invalidate, first shipped in
4.7.0; 4.6.x never got it). Zero RCOutput/bdshot/shared_dma commits after
the Copter-4.7.0 tag: nothing to upgrade to.

Precedent proving the mechanism class: PR 20442 (tridge 2022, "vehicles
falling out of the sky", H743 flash-storage lockups; 32-bit timer TIM2/TIM5
timeout wraparound made stalls catastrophic; fixed 4.2/4.4-era).

Leading hypothesis from 4.7.0 code reading (hypothesis, not documented
incident): bidirectional-DShot capture contention collapsing a 2-motor
group. Mechanics: (a) dshot_send refuses per-group when group.dshot_state
is stuck mid-transaction: the whole group silently misses frames while
others run; (b) bdshot does whole-group pwmStop/pwmStart each cycle, so a
capture problem on the single BIDIR pin (M5 on TIM3, M7 on TIM2) disturbs
both motors of that group; (c) hwdef DMA_NOSHARE covers only UP streams;
the bdshot input-capture streams (TIM3_CH3, TIM2_CH3, TIM1_CH1/CH3) are
shareable and un-prioritized. TIM1 group is most robust (2 BIDIR channels,
APB2 advanced timer, first in allocation order): matches "1-4 never failed".

Evidence that decides it (what devs ask for): full .bin with RCOU vs
ESC[5..8] telemetry (FC stopped commanding vs ESC dropped), @SYS/dma.txt +
timers.txt, bdshot error rates before the event, params MOT_PWM_TYPE,
SERVO_BLH_BDMASK, SERVO_DSHOT_ESC, SERVO_DSHOT_RATE.

Discriminating experiments: SERVO_BLH_BDMASK=0 on a test frame (bdshot off:
losses stop => capture/reset path implicated); hwdef variant with TIM2/TIM3
CH streams added to DMA_NOSHARE, or BIDIR moved off the 2-motor groups.

Next: customer params first (protocol config decides everything), crash
logs, then targeted dev question to andyp1per (drafted, awaiting user ok).

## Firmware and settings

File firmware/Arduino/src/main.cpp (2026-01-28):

// Order matters: STM32FreeRTOS wants its header first
#include <STM32FreeRTOS.h>
#include <Arduino.h>
#include <Adafruit_NeoPixel.h>

// -------------------- Hardware config --------------------
#define MATRIX_PIN PA2 // WS2812 data pin
#define MATRIX_W 4
#define MATRIX_H 4
#define NUM_PIXELS (MATRIX_W * MATRIX_H)

#define BLUE_LED PB15  // heartbeat LED BLUE
#define RED_LED PD15   // input indicator LED RED
#define GREEN_LED PD11 // spare LED GREEN

#define USER_INPUT PB3 // USER button / input (PB3, INTERNAL PULL-UP)

static const bool SERPENTINE = true;

// -------------------- NeoPixel object --------------------
Adafruit_NeoPixel strip(NUM_PIXELS, MATRIX_PIN, NEO_GRB + NEO_KHZ800);

// -------------------- Global screen state --------------------
volatile uint8_t g_currentScreen = 0; // which "screen" (pattern) is active

// -------------------- Helpers --------------------
static inline uint16_t xy(uint8_t x, uint8_t y)
{
  if (x >= MATRIX_W || y >= MATRIX_H)
    return 0;

  if (SERPENTINE && (y & 0x01))
  {
    // odd row: reversed order
    return y * MATRIX_W + (MATRIX_W - 1 - x);
  }
  else
  {
    return y * MATRIX_W + x;
  }
}

static inline uint32_t rgb(uint8_t r, uint8_t g, uint8_t b)
{
  return strip.Color(r, g, b);
}

// Simple HSV → RGB (for one of the screens)
uint32_t hsvToRgb(float h, float s, float v)
{
  float r, g, b;

  int i = int(h * 6.0f);
  float f = h * 6.0f - i;
  float p = v * (1.0f - s);
  float q = v * (1.0f - f * s);
  float t = v * (1.0f - (1.0f - f) * s);

  switch (i % 6)
  {
  case 0:
    r = v;
    g = t;
    b = p;
    break;
  case 1:
    r = q;
    g = v;
    b = p;
    break;
  case 2:
    r = p;
    g = v;
    b = t;
    break;
  case 3:
    r = p;
    g = q;
    b = v;
    break;
  case 4:
    r = t;
    g = p;
    b = v;
    break;
  case 5:
    r = v;
    g = p;
    b = q;
    break;
  }

  return strip.Color(
      (uint8_t)(r * 255.0f),
      (uint8_t)(g * 255.0f),
      (uint8_t)(b * 255.0f));
}

// Fill entire matrix with one color
void fillMatrix(uint8_t r, uint8_t g, uint8_t b)
{
  uint32_t c = rgb(r, g, b);
  for (uint16_t i = 0; i < NUM_PIXELS; i++)
  {
    strip.setPixelColor(i, c);
  }
  strip.show();
}

// -------------------- Effects (startup only) --------------------

// 1) Color wipe row by row
void effectColorWipe()
{
  Serial.println("[Effect] ColorWipe");
  const uint32_t colors[] = {
      rgb(255, 0, 0),
      rgb(0, 255, 0),
      rgb(0, 0, 255),
      rgb(255, 255, 0)};

  for (uint8_t c = 0; c < 4; c++)
  {
    strip.clear();
    strip.show();
    vTaskDelay(pdMS_TO_TICKS(100));

    for (uint8_t y = 0; y < MATRIX_H; y++)
    {
      for (uint8_t x = 0; x < MATRIX_W; x++)
      {
        strip.setPixelColor(xy(x, y), colors[c]);
        strip.show();
        vTaskDelay(pdMS_TO_TICKS(40));
      }
    }

    vTaskDelay(pdMS_TO_TICKS(400));
  }
}

// 2) Bouncing dot perimeter
void effectBouncingPerimeter()
{
  Serial.println("[Effect] Bouncing perimeter");

  const uint8_t steps = 40; // how long to run
  uint8_t x = 0, y = 0;
  int8_t dx = 1, dy = 0; // start moving right

  for (uint8_t step = 0; step < steps; step++)
  {
    strip.clear();
    strip.setPixelColor(xy(x, y), rgb(0, 255, 255));
    strip.show();
    vTaskDelay(pdMS_TO_TICKS(80));

    // Move around the border of the 4x4
    if (dx == 1 && x == MATRIX_W - 1)
    {
      dx = 0;
      dy = 1; // turn down
    }
    else if (dy == 1 && y == MATRIX_H - 1)
    {
      dx = -1;
      dy = 0; // turn left
    }
    else if (dx == -1 && x == 0)
    {
      dx = 0;
      dy = -1; // turn up
    }
    else if (dy == -1 && y == 0)
    {
      dx = 1;
      dy = 0; // turn right
    }

    x += dx;
    y += dy;
  }
}

// 3) Simple rainbow cycle (using old wheel for variety)
uint32_t wheel(uint8_t pos)
{
  pos = 255 - pos;
  if (pos < 85)
  {
    return rgb(255 - pos * 3, 0, pos * 3);
  }
  else if (pos < 170)
  {
    pos -= 85;
    return rgb(0, pos * 3, 255 - pos * 3);
  }
  else
  {
    pos -= 170;
    return rgb(pos * 3, 255 - pos * 3, 0);
  }
}

void effectRainbow()
{
  Serial.println("[Effect] Rainbow");
  for (uint16_t t = 0; t < 256; t += 4)
  {
    for (uint8_t y = 0; y < MATRIX_H; y++)
    {
      for (uint8_t x = 0; x < MATRIX_W; x++)
      {
        uint8_t idx = (x + y * MATRIX_W);
        uint8_t pos = (idx * 256 / NUM_PIXELS + t) & 0xFF;
        strip.setPixelColor(xy(x, y), wheel(pos));
      }
    }
    strip.show();
    vTaskDelay(pdMS_TO_TICKS(40));
  }
}

// -------------------- "Screens" for final static mode --------------------
// Screen 0: solid blue
// Screen 1: solid green
// Screen 2: solid yellow
// Screen 3: magenta
// Screen 4: cyan gradient
#define NUM_SCREENS 12

void drawScreen(uint8_t screen)
{
  screen %= NUM_SCREENS; // safety

  switch (screen)
  {
  case 0: // blue
    fillMatrix(0, 0, 255);
    break;

  case 1: // OFF
    fillMatrix(0, 0, 0);
    break;

  case 2: // green
    fillMatrix(0, 255, 0);
    break;

  case 3: // yellow
    fillMatrix(255, 255, 0);
    break;

  case 4: // magenta
    fillMatrix(255, 0, 255);
    break;

  case 5: // magenta
    fillMatrix(255, 0, 255);
    break;

  case 6: // 
    fillMatrix(255, 120, 255);
    break;

  case 7: // 
    fillMatrix(30, 30, 0);
    break;

  case 8: // 
    fillMatrix(0, 100, 0);
    break;

  case 9: //
    effectColorWipe();
    break;

  case 10: //
    effectBouncingPerimeter();
    break;

  case 11: //
    effectRainbow();
    break;

  case 12: // simple cyan-ish gradient across matrix
  default:
    for (uint8_t y = 0; y < MATRIX_H; y++)
    {
      for (uint8_t x = 0; x < MATRIX_W; x++)
      {
        float h = 0.5f + (x + y) * 0.02f; // around cyan, slight variation
        if (h > 1.0f)
          h -= 1.0f;
        uint32_t c = hsvToRgb(h, 0.6f, 0.9f);
        strip.setPixelColor(xy(x, y), c);
      }
    }
    strip.show();
    break;
  }

  Serial.print("[Screen] Now showing screen ");
  Serial.println(screen);
}

// -------------------- FreeRTOS tasks --------------------

void TaskStatusLED(void *pvParameters)
{
  (void)pvParameters;

  pinMode(GREEN_LED, OUTPUT);
  pinMode(BLUE_LED, OUTPUT);

  // GREEN on
  digitalWrite(GREEN_LED, HIGH);
  vTaskDelay(2000);
  digitalWrite(GREEN_LED, LOW);

  for (;;)
  {
    // BLUE heartbeat pulse
    digitalWrite(BLUE_LED, HIGH);
    vTaskDelay(20000);
    digitalWrite(BLUE_LED, LOW);
    vTaskDelay(2000);
  }
}

void TaskInputRead(void *pvParameters)
{
  (void)pvParameters;

  pinMode(RED_LED, OUTPUT);
  pinMode(USER_INPUT, INPUT_PULLUP); // internal pull-up

  int lastState = digitalRead(USER_INPUT);

  for (;;)
  {
    int state = digitalRead(USER_INPUT);

    // RED = input state
    digitalWrite(RED_LED, !state ? HIGH : LOW);

    // Detect button press: HIGH -> LOW (active-low button)
    if (lastState == HIGH && state == LOW)
    {
      // Advance screen index
      uint8_t next = g_currentScreen + 1;
      if (next >= NUM_SCREENS)
        next = 0;
      g_currentScreen = next;

      Serial.print("[Button] Press detected, new screen = ");
      Serial.println(next);
    }

    lastState = state;
    vTaskDelay(pdMS_TO_TICKS(40));
  }
}

// Task that owns the matrix / effects
void TaskMatrix(void *pvParameters)
{
  (void)pvParameters;

  strip.begin();
  strip.setBrightness(30);
  strip.clear();
  strip.show();

  Serial.println("[Matrix] Task started");

  // ---- Startup effects run once ----
  effectColorWipe();
  effectBouncingPerimeter();
  effectRainbow();
  fillMatrix(100, 100, 100);

  // Pause briefly, then go to screen 0 (blue)
  fillMatrix(0, 0, 0);

  vTaskDelay(pdMS_TO_TICKS(5000));
  g_currentScreen = 0;
  drawScreen(g_currentScreen); // initial screen

  // ---- Final static mode: only change on button press ----
  uint8_t lastScreen = g_currentScreen;

  for (;;)
  {
    uint8_t current = g_currentScreen;

    if (current != lastScreen)
    {
      lastScreen = current;
      drawScreen(current); // update matrix ONCE, then it stays fixed
    }

    // short poll delay; DOES NOT redraw unless screen changed
    vTaskDelay(pdMS_TO_TICKS(50));
  }
        
}

// -------------------- Arduino entry points --------------------
void setup()
{
  delay(500); // small settle
  Serial.begin(115200);
  Serial.println("\n=== LED Matrix RTOS Boot ===");

  xTaskCreate(
      TaskStatusLED,
      "status",
      256,
      nullptr,
      2,
      nullptr);

  xTaskCreate(
      TaskInputRead,
      "input",
      256,
      nullptr,
      1,
      nullptr);

  xTaskCreate(
      TaskMatrix,
      "matrix",
      512,
      nullptr,
      2,
      nullptr);

  vTaskStartScheduler();

  while (1)
  {
  }
}

void loop()
{
  // Not used with FreeRTOS (everything is in tasks)
}

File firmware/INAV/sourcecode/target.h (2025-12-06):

/*
 * AirBrain H743 (Maverick) target for INAV
 *
 * Board: STM32H743VIH6
 * IMU:   ICM-42688-P on SPI1
 * MAG:   LIS2MDL on I2C1
 * BARO:  DPS368 on I2C1
 * FLASH: W25N01G (SPI-NAND) on SPI2  [NOT ENABLED YET IN THIS HEADER]
 * PSU:   3–10S LiPo, onboard 5V/2A and 10V/2.5A regulators
 * UARTs: 1,2,3,4,5,7,8 + VCP
 * PWM:   8 motor outputs, DShot capable
 *
 * This file is intentionally written in the style of existing INAV H743 targets
 * (e.g. MATEKH743) so it has the best chance to compile in INAV with minimal
 * edits.
 */

#pragma once

#define TARGET_BOARD_IDENTIFIER "AIRB"
#define USBD_PRODUCT_STRING "AIRBRAINH743"

#define USE_TARGET_CONFIG

/****************************************
 * LEDS / BEEPER
 ****************************************/
#define LED0 PB15
#define LED1 PD11
#define LED2 PD15

#define BEEPER PA15
#define BEEPER_INVERTED
#define BEEPER_PWM_FREQUENCY 2500

/****************************************
 * SPI BUSES / IMU / (future flash)
 ****************************************/

// ---- SPI1 : IMU ----// ---- SPI1 : IMU ----
#define USE_SPI
#define USE_SPI_DEVICE_1
#define SPI1_SCK_PIN PA5
#define SPI1_MISO_PIN PA6
#define SPI1_MOSI_PIN PA7

// ICM-42688-P, but INAV 8 expects the 42605 macro names (but seen these macros in DAKEFPVF722X8/target.h)
#define USE_IMU_ICM42688P
#define ICM42688P_SPI_BUS BUS_SPI1
#define ICM42688P_CS_PIN PA3
#define ICM42688P_EXTI_PIN PC6
#define IMU_ICM42688P_ALIGN CW90_DEG

/*

// Below works in INAV v8
#define USE_IMU_ICM42605
#define ICM42605_SPI_BUS BUS_SPI1
#define ICM42605_CS_PIN PA3
#define ICM42605_EXTI_PIN PC6
#define IMU_ICM42605_ALIGN CW90_DEG

*/

// ---- SPI2 : onboard NAND flash (blackbox) ----
// NOTE: INAV mainly supports NOR flash / SD cards today.
// The AirBrain uses a W25N01G SPI-NAND (128 MByte).
// We'll declare SPI2 bus pins so the bus exists,
// but we DO NOT enable flash logging yet to avoid build breakage.
//
// You can add USE_FLASHFS / USE_xxx later once INAV has/accepts a NAND driver.
//
#define USE_SPI_DEVICE_2
#define SPI2_SCK_PIN PD3
#define SPI2_MISO_PIN PB14
#define SPI2_MOSI_PIN PC3
// Flash CS is on PD4 (for future enablement):
// #define FLASH_CS_PIN         PD4
// #define FLASH_SPI_BUS        BUS_SPI2
// #define ENABLE_BLACKBOX_LOGGING_ON_SPIFLASH_BY_DEFAULT
// (commented out for first-pass build safety)

// ---- SPI3 : auxiliary header / expansion ----
// Expose SPI3 (optional external peripherals)
// Keeping this consistent with style in other targets
#define USE_SPI_DEVICE_3
#define SPI3_SCK_PIN PE12
#define SPI3_MISO_PIN PE5
#define SPI3_MOSI_PIN PE6

/****************************************
 * I2C BUSES / BARO / MAG
 ****************************************/

#define USE_I2C
#define USE_I2C_DEVICE_1
#define I2C1_SCL PB6
#define I2C1_SDA PB7

// Barometer (Infineon DPS368)
#define USE_BARO
#define USE_BARO_DPS310  // DPS310 driver also covers DPS368
#define BARO_I2C_BUS BUS_I2C1

// Magnetometer (LIS2MDL)
#define USE_MAG
#define USE_MAG_LIS3MDL  // LIS2MDL is register-compatible enough
#define MAG_I2C_BUS BUS_I2C1

// (Optional future sensors on I2C1: rangefinder, pitot, etc. can be added
// later)

/****************************************
 * UARTs / SERIAL
 ****************************************/

#define USE_VCP

#define USE_UART1
#define UART1_TX_PIN PA9
#define UART1_RX_PIN PA10

#define USE_UART2
#define UART2_TX_PIN PD5
#define UART2_RX_PIN PD6

#define USE_UART3
#define UART3_TX_PIN PD8
#define UART3_RX_PIN PD9

#define USE_UART4
#define UART4_TX_PIN PB9
#define UART4_RX_PIN PB8

#define USE_UART5
#define UART5_TX_PIN PB13
#define UART5_RX_PIN PB12

// UART6 not routed on this board, so we do NOT define USE_UART6

#define USE_UART7
#define UART7_TX_PIN PE8  // present on header according to pinout
#define UART7_RX_PIN PE7

#define USE_UART8
#define UART8_TX_PIN PE1
#define UART8_RX_PIN PE0

// We are not enabling SOFTSERIAL by default (can add later if you want a
// software port)

#define SERIAL_PORT_COUNT 8

// Board default: CRSF/ELRS on a hardware UART is common,
// but unlike Matek we won't force SERIALRX defaults here.
// That can be done in target defaults / diff later.
// (So we skip DEFAULT_RX_TYPE / SERIALRX_PROVIDER / SERIALRX_UART for now)

/****************************************
 * LED STRIP / PINIO
 ****************************************/

#define USE_LED_STRIP
#define WS2811_PIN PA2  // addressable LED strip output

#define USE_PINIO
#define USE_PINIOBOX
// The board exposes an AUX transistor / USER pin on PB3, so map it:
#define PINIO1_PIN PB3
// If you have a second controllable transistor output, add PINIO2_PIN <pin>
// here

/****************************************
 * POWER / ADC
 ****************************************/
// NOTE:
// INAV expects ADC channel mapping (ADC_CHANNEL_n_PIN etc.).
// That mapping is specific to MCU pin -> ADC channel numbers.
// We don't guess here, because a wrong map breaks voltage/current sensing
// and can block arming in some modes.
//
// For first-pass bring-up / build sanity, we intentionally DO NOT
// enable USE_ADC yet. You can add this once you map:
//
//   - VBAT sense (PC4 on your board)
//   - CURRENT sense (PC5 on your board)
//
// Example for later (do NOT paste until you confirm channels):
//
// #define USE_ADC
// #define ADC_INSTANCE                ADC1
//
// #define ADC_CHANNEL_1_PIN           PC4   // VBAT
// #define ADC_CHANNEL_2_PIN           PC5   // CURRENT
//
// #define VBAT_ADC_CHANNEL            ADC_CHN_1
// #define CURRENT_METER_ADC_CHANNEL   ADC_CHN_2
//
// #define DEFAULT_VOLTAGE_METER_SOURCE VOLTAGE_METER_ADC
// #define DEFAULT_CURRENT_METER_SOURCE CURRENT_METER_ADC
// #define DEFAULT_VOLTAGE_METER_SCALE 150
// #define CURRENT_METER_SCALE         99

/****************************************
 * MOTOR OUTPUT / DSHOT
 ****************************************/

// AirBrain provides 8 motor outputs and supports DShot ESCs
#define MAX_PWM_OUTPUT_PORTS 8
#define USE_DSHOT
#define USE_SERIAL_4WAY_BLHELI_INTERFACE

// We do NOT define Betaflight-style MOTORx_PIN or TIMER_PIN_MAPPING here.
// INAV H7 targets don't use that macro in the .h.
// Timer routing can go in target.c later if needed.

/****************************************
 * GPIO MASKS
 ****************************************/
// Matek defines these to indicate what ports are available for resource
// remapping. For first pass we'll expose full ports A..E except for JTAG SWD
// pins if needed. You can tighten these later if INAV maintainers ask.

#define TARGET_IO_PORTA 0xffff
#define TARGET_IO_PORTB 0xffff
#define TARGET_IO_PORTC 0xffff
#define TARGET_IO_PORTD 0xffff
#define TARGET_IO_PORTE 0xffff

/****************************************
 * DEFAULT FEATURES
 ****************************************/
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

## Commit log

2025-10-31 update ardupilot bin
    [30x30_to_20x20.step]
2025-11-05 update pictures and datasheet to v1.1.0
    [30x30_to_20x20_short.step]
2026-01-28 added PlatformIo (Arduino)
2026-02-25 added Ardupilot 4.6 as frozen binary build (for 4.7 current qgroundcontrol is not up to date yet)
2026-05-08 docs(datasheet): publish v2.1 (dimensions, regulatory language, USB-C spec, pinout legend, Inter font)
2026-05-08 docs(readme): full rewrite with switching guide and recovery pointer
2026-05-08 docs(readme): drop overly defensive lines (no-schematics-here, INAV not-advertised)
2026-05-08 chore(firmware/ardupilot/sourcecode): refresh from ArduPilot/ardupilot@e080acb + add upstream pinouts/README/defaults
    [defaults.parm]
2026-05-08 docs(datasheet): publish v2.1.1 (per-stack switching guide and build-from-source links)
2026-06-17 docs(PX4): add QGC Daily Developer Build flow + iis2mdc mag note
    Step 2 of the PX4 install section now offers two routes:
    - Option A: QGC Daily, Developer Build (master) - recommended until v1.18 stable
    - Option B: manual .px4 download from PX4 CI S3
    Also adds a verification note that LIS2MDL is detected by PX4 iis2mdc driver
    out of the box, confirmed with Julian Oes 2026-06-16.
2026-06-22 datasheet: v2.4, quick-spec strip on cover
    Moved Mounting/Board/Pinout strip from page 2 to the cover, added MCU
    field (STM32H7, 480 MHz), removed cover-footer block. Page-1 footer
    suppressed via shared @page :first rule. Strip layout parallel to
    AirPilot H743 v0.10.
2026-08-26 fw-pm: timer-group crash investigation opened + upstream sweep logged (leading hypothesis bdshot capture contention; 4.7.0 has all known fixes)
2026-08-26 fw-pm: Andy reply logged; DMA-contention hypothesis refuted (UP+CH shared per timer on H7); blocked on customer logs
2026-09-01 fw-pm: Sabena timer-crash analysis log
2026-09-01 fw-pm: px4 target added; mission-persistence root cause (SYS_DM_BACKEND=1 in board defaults)
